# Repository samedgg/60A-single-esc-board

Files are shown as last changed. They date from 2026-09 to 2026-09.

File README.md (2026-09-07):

# Single ESC Board (AT32F421)

This project is a compact **Single ESC (Electronic Speed Controller)** board designed for brushless motor applications.

---

## ESC Topology

At the core of the power delivery system is a standard 3-phase inverter topology. This architecture allows for precise electronic commutation, enabling smooth, reliable, and efficient control of the BLDC motor's speed and torque.



### MOSFET Network
The power stage utilizes six high-efficiency Infineon BSC010N04LSI N-channel MOSFETs configured in a standard 3-phase bridge (High-Side and Low-Side half-bridges for phases A, B, and C). Driven by high-frequency PWM signals, this network effectively inverts the DC supply voltage into the sequenced multiphase waveforms required for precise motor commutation, while keeping switching losses and thermal dissipation to a minimum.

### BEMF Network
To facilitate sensorless motor control, the design integrates a Back-Electromotive Force (BEMF) sensing circuit. This precision resistor divider network scales the high-voltage signals from the unenergized (floating) motor phases down to a safe 3.3V logic level. This continuous feedback loop allows the microcontroller's ADC to accurately detect zero-crossing events, enabling the MCU to calculate the exact rotor position and synchronize commutation timing without the need for external Hall-effect sensors.

---

## 3D Views and Schematic
3d
3d back
schematic

---

## Layers

layers

l1

l2

l3

l4

---

## Bill of Materials

| Designator | Component | Description |
| :--- | :--- | :--- |
| **U2** | AT32F421G8U7 | 32-bit ARM Cortex-M4 Microcontroller |
| **U1** | DRV8300DPWR | 3-Phase MOSFET Gate Driver |
| **Q1 - Q6** | BSC010N04LSI | 40V N-Channel Power MOSFET |
| **R22** | Shunt Resistor | Low-ohm current sensing resistor |
| **U3-U4** | TPS62933DRLR Buck Regulator | Power inductor for 9V/3.3V regulation |
| **C1 - C20** | SMD Ceramic Capacitors | Decoupling and input filter capacitors |

---

## IPC-2152 Analysis

Based on IPC-2152 standards evaluated via the Saturn PCB Toolkit, the continuous current-carrying capacity of this Single ESC board is rated at ~24.4A. This theoretical limit is determined by analyzing the narrowest bottleneck of the power delivery network (138 mils), which utilizes two parallel copper layers (L1 and L3) with a 2oz base copper weight.





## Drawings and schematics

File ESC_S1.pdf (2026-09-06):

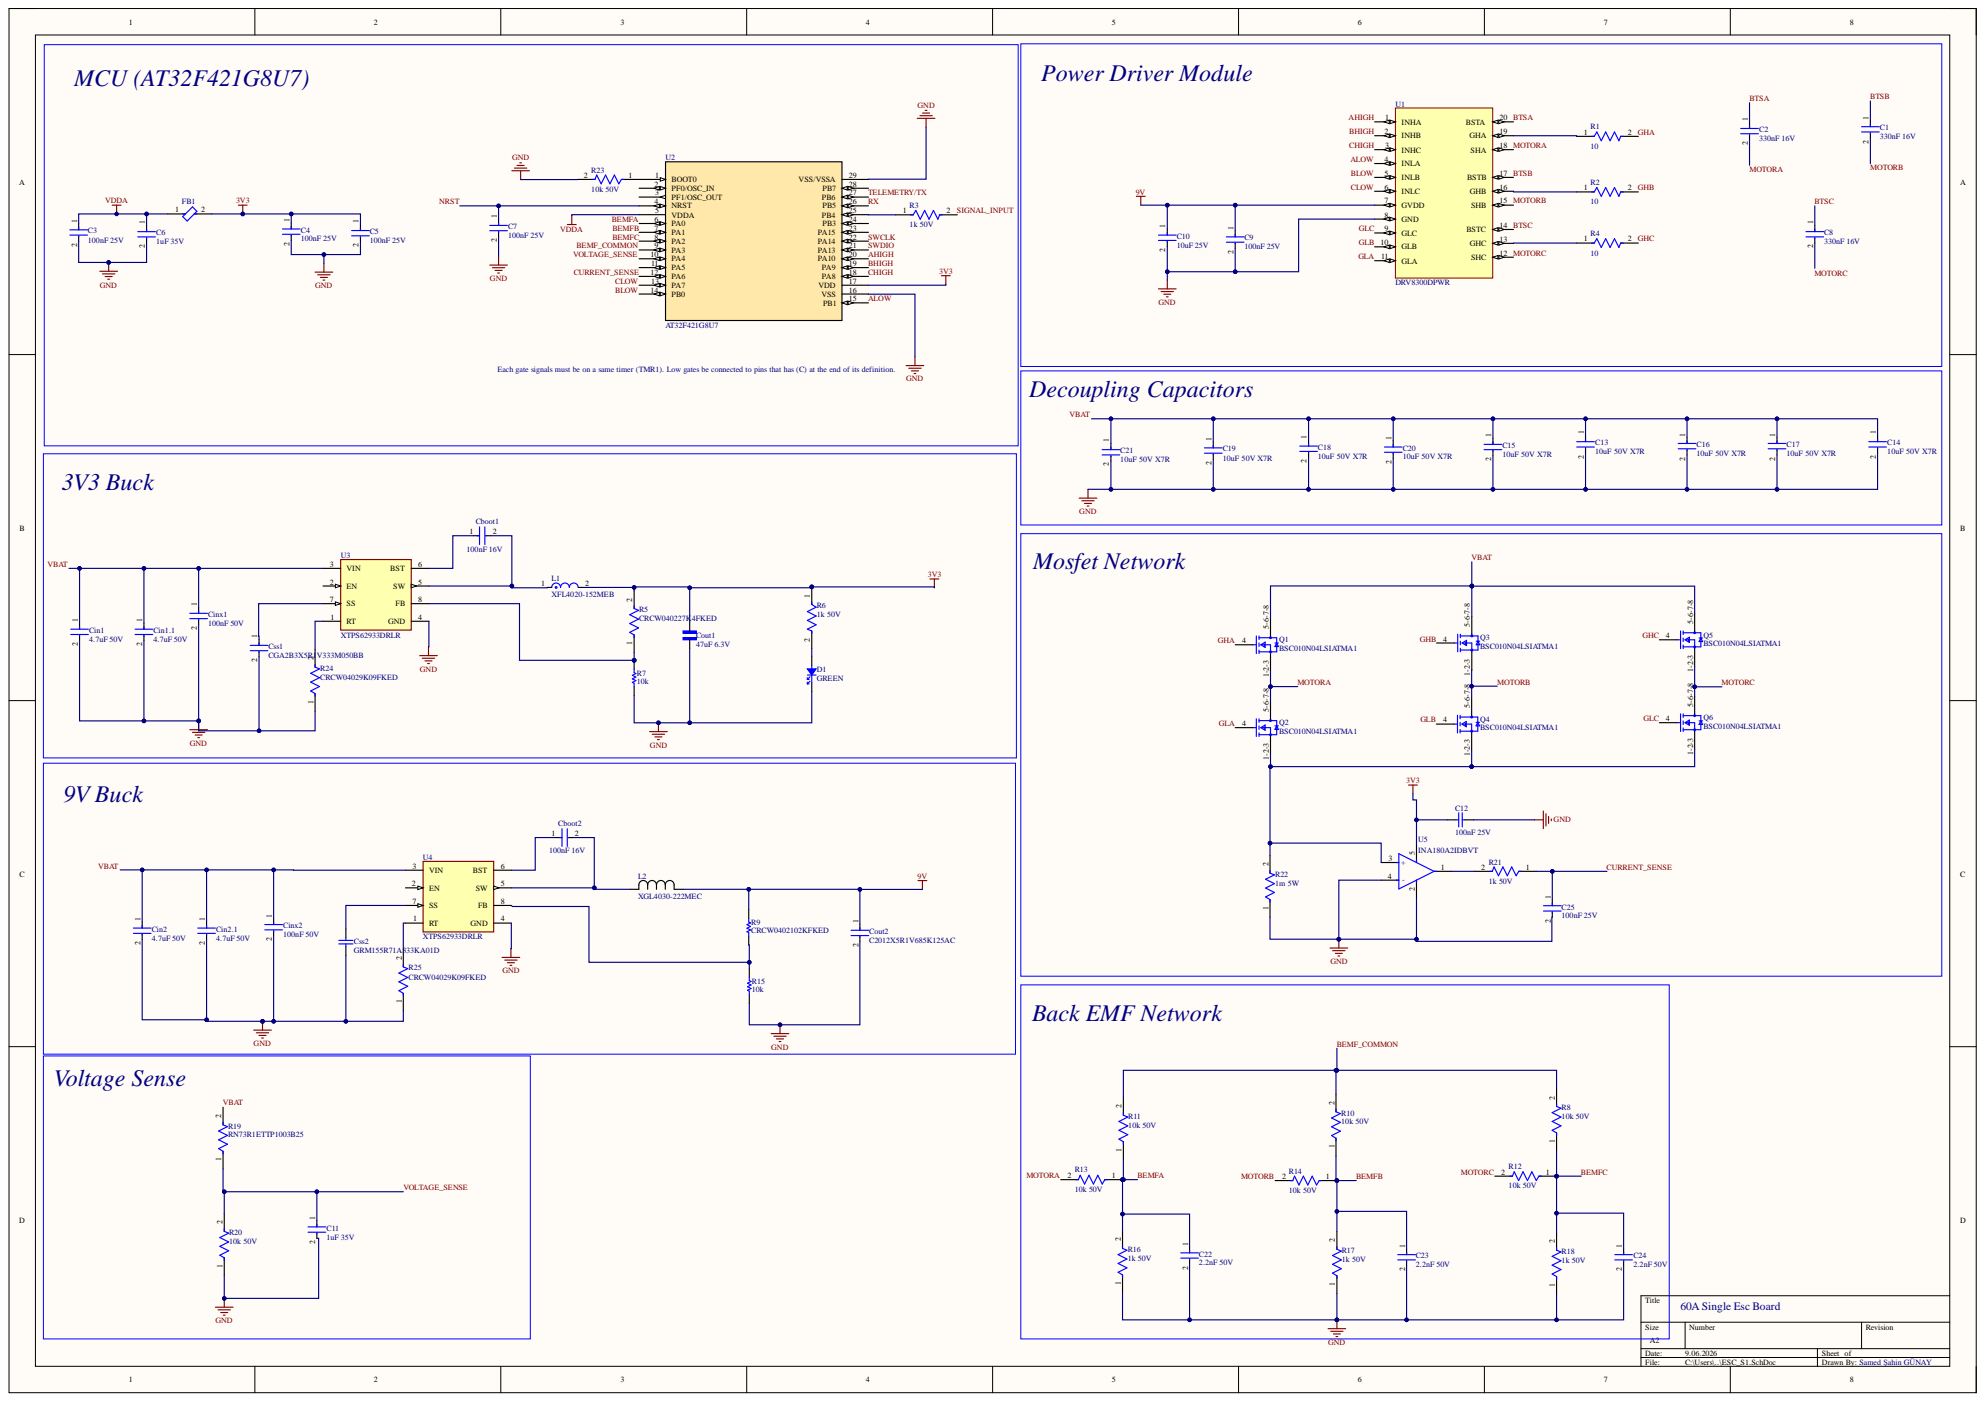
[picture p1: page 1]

Each gate signals must be on a same timer (TMR1). Low gates be connected to pins that has (C) at the end of its definition.

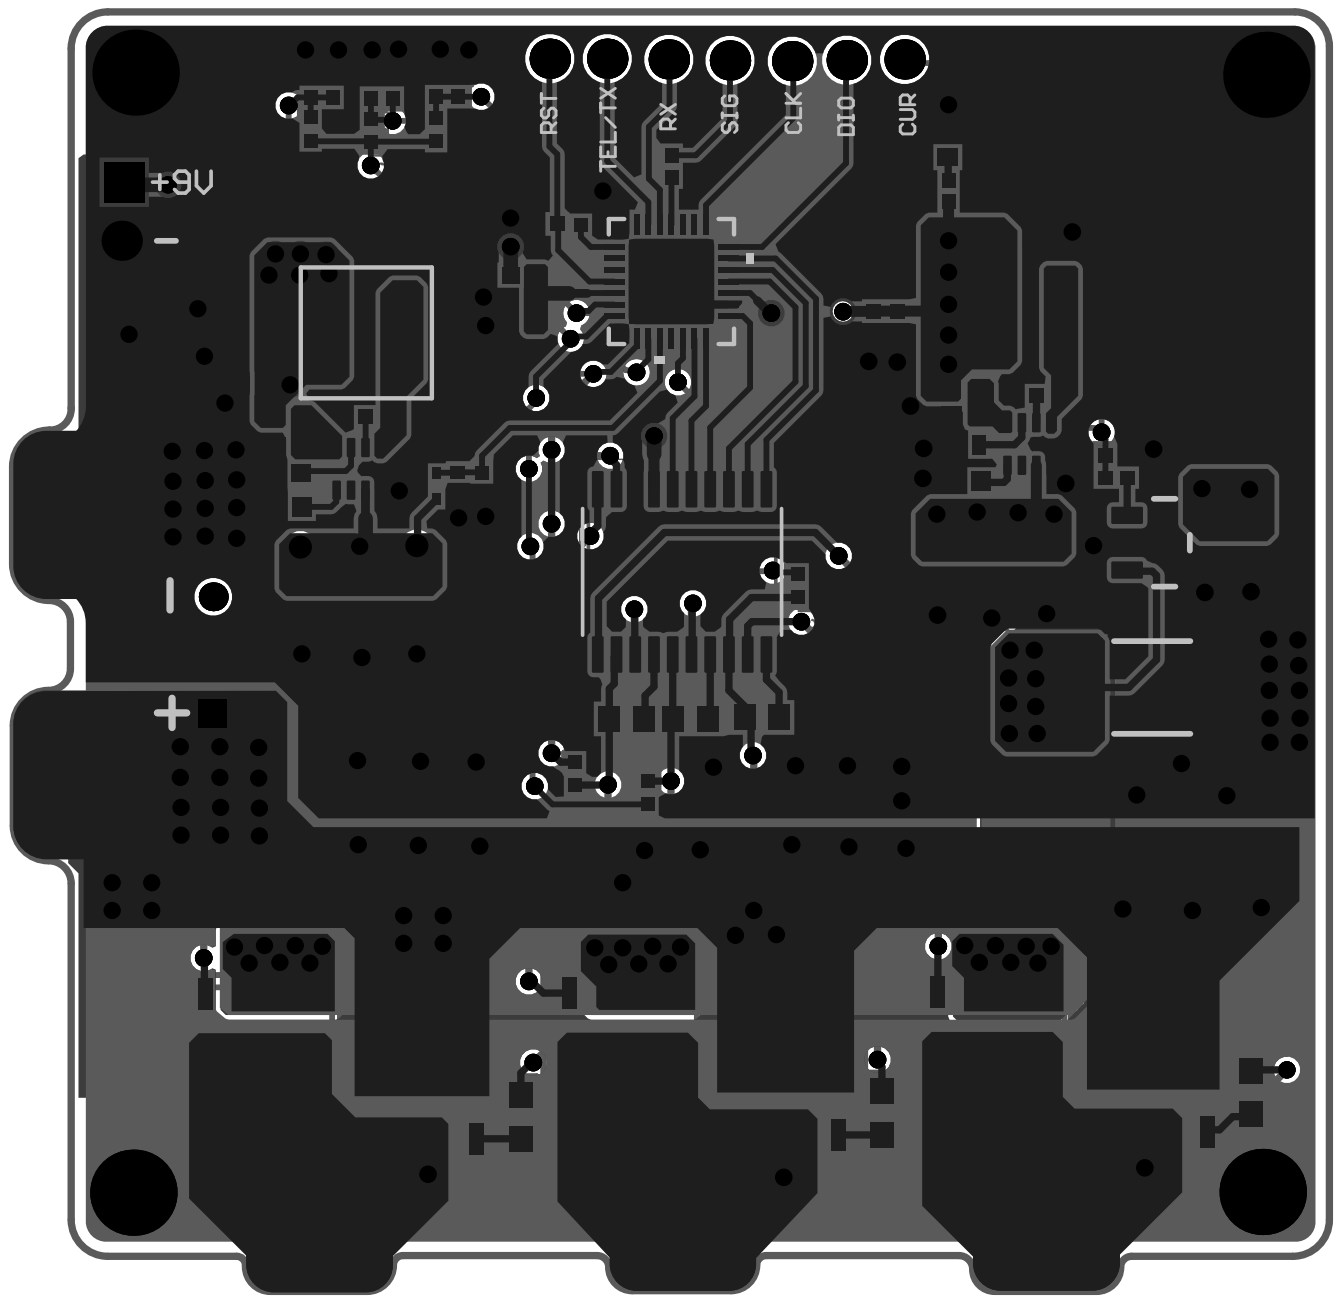
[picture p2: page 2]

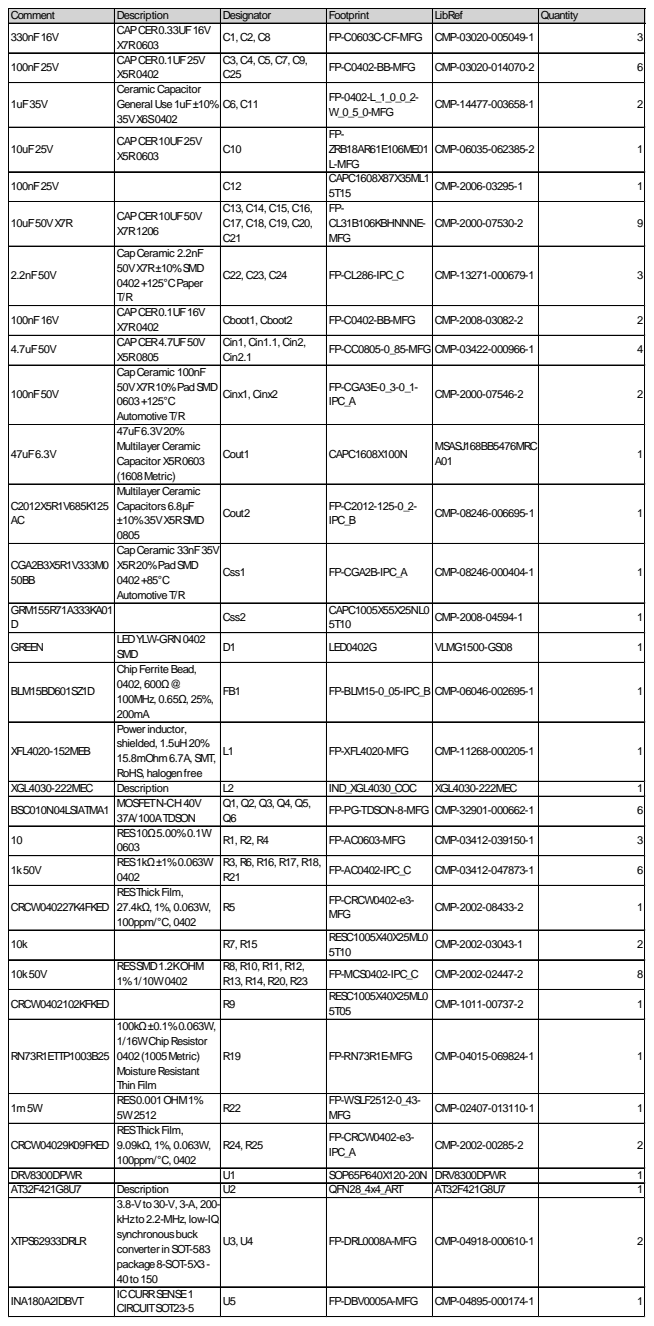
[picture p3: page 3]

Comment | Description | Designator | Footprint | LibRef | Quantity
330nF16V | CAPCER0.33UF16V X7R0603 | C1, C2, C8 | FP-C0603C-CF-MFG | CMP-03020-005049-1 | 3

100nF25V | CAPCER0.1UF25V X5R0402 | C3, C4, C5, C7, C9, C25 | FP-C0402-BB-MFG | CMP-03020-014070-2 | 6

1uF35V | Ceramic Capacitor General Use1uF±10% 35VX6S0402 | C6, C11 | FP-0402-L_1_0_0_2-W_0_5_0-MFG | CMP-14477-003658-1 | 2

10uF25V | CAPCER10UF25V X5R0603 | C10 | FP-ZRB18AR61E106ME01 L-MFG | CMP-06035-062385-2 | 1

100nF25V | | C12 | CAPC1608X87X35ML1 5T15 | CMP-2006-03295-1 | 1

10uF50VX7R | CAPCER10UF50V X7R1206 | C13, C14, C15, C16, C17, C18, C19, C20, C21 | FP-CL31B106KBHNNNE-MFG | CMP-2000-07530-2 | 9

2.2nF50V | CapCeramic 2.2nF 50VX7R±10%SMD 0402+125°CPaper T/R | C22, C23, C24 | FP-CL286-IPC_C | CMP-13271-000679-1 | 3

100nF16V | CAPCER0.1UF16V X7R0402 | Cboot1, Cboot2 | FP-C0402-BB-MFG | CMP-2008-03082-2 | 2

4.7uF50V | CAPCER4.7UF50V X5R0805 | Cin1, Cin1.1, Cin2, Cin2.1 | FP-CC0805-0_85-MFG | CMP-03422-000966-1 | 4

100nF50V | CapCeramic 100nF 50VX7R10%PadSMD 0603+125°C AutomotiveT/R | Cinx1, Cinx2 | FP-CGA3E-0_3-0_1-IPC_A | CMP-2000-07546-2 | 2

47uF6.3V | 47uF6.3V20% Multilayer Ceramic Capacitor X5R0603 (1608Metric) | Cout1 | CAPC1608X100N | MSASJ168BB5476MRC A01 | 1

C2012X5R1V685K125 AC | Multilayer Ceramic Capacitors 6.8μF ±10%35VX5RSMD 0805 | Cout2 | FP-C2012-125-0_2-IPC_B | CMP-08246-006695-1 | 1

CGA2B3X5R1V333M0 50BB | CapCeramic 33nF35V X5R20%PadSMD 0402+85°C AutomotiveT/R | Css1 | FP-CGA2B-IPC_A | CMP-08246-000404-1 | 1

GRM155R71A333KA01 D | | Css2 | CAPC1005X55X25NL0 5T10 | CMP-2008-04594-1 | 1

GREEN | LEDYLW-GRN0402 SMD | D1 | LED0402G | VLMG1500-GS08 | 1

BLM15BD601SZ1D | ChipFerriteBead, 0402, 600Ω@ 100MHz, 0.65Ω, 25%, 200mA | FB1 | FP-BLM15-0_05-IPC_B | CMP-06046-002695-1 | 1

XFL4020-152MEB | Power inductor, shielded, 1.5uH20% 15.8mOhm6.7A, SMT, RoHS, halogenfree | L1 | FP-XFL4020-MFG | CMP-11268-000205-1 | 1

XGL4030-222MEC | Description | L2 | IND_XGL4030_COC | XGL4030-222MEC | 1
BSC010N04LSIATMA1 | MOSFETN-CH40V 37A/100ATDSON | Q1, Q2, Q3, Q4, Q5, Q6 | FP-PG-TDSON-8-MFG | CMP-32901-000662-1 | 6

10 | RES10Ω5.00%0.1W 0603 | R1, R2, R4 | FP-AC0603-MFG | CMP-03412-039150-1 | 3

1k50V | RES1kΩ±1%0.063W 0402 | R3, R6, R16, R17, R18, R21 | FP-AC0402-IPC_C | CMP-03412-047873-1 | 6

CRCW040227K4FKED | RESThickFilm, 27.4kΩ, 1%, 0.063W, 100ppm/°C, 0402 | R5 | FP-CRCW0402-e3-MFG | CMP-2002-08433-2 | 1

10k | | R7, R15 | RESC1005X40X25ML0 5T10 | CMP-2002-03043-1 | 2

10k50V | RESSMD1.2KOHM 1%1/10W0402 | R8, R10, R11, R12, R13, R14, R20, R23 | FP-MCS0402-IPC_C | CMP-2002-02447-2 | 8

CRCW0402102KFKED | | R9 | RESC1005X40X25ML0 5T05 | CMP-1011-00737-2 | 1

RN73R1ETTP1003B25 | 100kΩ±0.1%0.063W, 1/16WChipResistor 0402(1005Metric) MoistureResistant ThinFilm | R19 | FP-RN73R1E-MFG | CMP-04015-069824-1 | 1

1m5W | RES0.001OHM1% 5W2512 | R22 | FP-WSLF2512-0_43-MFG | CMP-02407-013110-1 | 1

CRCW04029K09FKED | RESThickFilm, 9.09kΩ, 1%, 0.063W, 100ppm/°C, 0402 | R24, R25 | FP-CRCW0402-e3-IPC_A | CMP-2002-00285-2 | 2

DRV8300DPWR | | U1 | SOP65P640X120-20N | DRV8300DPWR | 1
AT32F421G8U7 | Description | U2 | QFN28_4x4_ART | AT32F421G8U7 | 1
XTPS62933DRLR | 3.8-Vto30-V, 3-A, 200-kHzto2.2-MHz, low-IQ synchronousbuck converter inSOT-583 package8-SOT-5X3-40to150 | U3, U4 | FP-DRL0008A-MFG | CMP-04918-000610-1 | 2

INA180A2IDBVT | ICCURRSENSE1 CIRCUITSOT23-5 | U5 | FP-DBV0005A-MFG | CMP-04895-000174-1 | 1
